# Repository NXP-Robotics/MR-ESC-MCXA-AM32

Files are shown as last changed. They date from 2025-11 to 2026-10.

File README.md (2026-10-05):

# NXP AM32 ESC based on the MCXA133

MR-ESC-MCXA-AM32 is a proof of concept Drone motor ESC (Electronic Speed Controller) motor controller, 
using NXP MCXA133 MCU and running the open-source AM32 software.
A limited number of prototype hardware samples may be available, please contact your local NXP representative. 

> [!NOTE]
> AM32 support for the MCXA133 has already been merged in mainline AM32: [AM32 application](https://github.com/am32-firmware/am32) and [AM32 bootloader](https://github.com/am32-firmware/AM32-bootloader).
> Build target for MCXA133 in main application is "FRDM_A153" and "AM32_A153_BOOTLOADER_PB2" in bootloader.
>
> Hex files can be downloaded from the official AM32 configurator: [AM32 configurator downloads](https://am32.ca/downloads)            
> AM32 Motor Control Application: AM32_FRDM_A153_x.xx.hex; AM32 Bootloader: AM32_A153_BOOTLOADER_PB2_Vxx.hex
>
> Flash board using the 6-pin JST-SH connector ([Pixhawk Debug Mini](https://docs.px4.io/main/en/debug/swd_debug#pixhawk-debug-mini))
> Do note that when flashing with MCU-LINK, pin 3 should be removed.
> 
> Design files are made with KiCAD.

> [!IMPORTANT]
This design is not supported by NXP motor control framework tools (it could of course be made to run with modifications)

MR-ESC-MCXA-AM32 with wires

<details>
<summary><h1><strong>More pictures</strong></h1></summary>

MR-ESC-MXCA-AM32 top
MR-ESC-MXCA-AM32 bottom
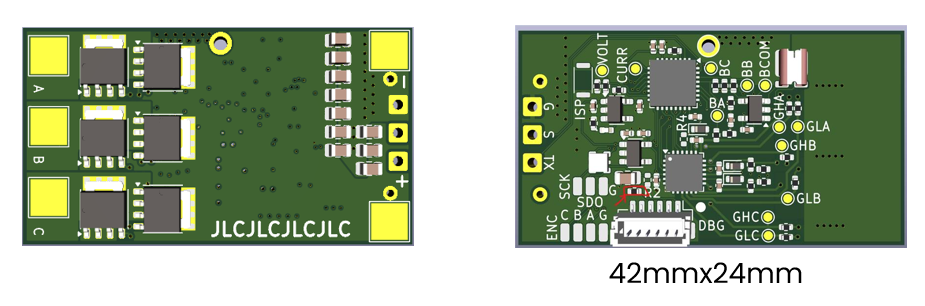
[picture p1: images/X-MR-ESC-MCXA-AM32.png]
Rendering of x-MR-ESC-MCXA-AM32 board


</details>

## Board overview

All pin data below comes from the KiCad design files in this repository.

Each card shows, per pin, the **function**, the **net name in the schematic** and the **MCU pad**
the signal ends up on. Most connections are solder pads; the only connector is the debug port.

<!-- overview:top -->
<picture>
  <source media="(prefers-color-scheme: dark)" srcset="images/overview-top-dark.svg">
  MR-ESC-MCXA-AM32 top view with labels
</picture>
<!-- /overview -->

<!-- overview-list:top -->
Not visible here: [PWR BATTERY](#esc-pwr-battery) (bottom view) · [MOTOR PHASES](#esc-motor-phases) (bottom view)
<!-- /overview-list -->

Bottom side, with the battery and motor pads:

<!-- overview:bottom -->
<picture>
  <source media="(prefers-color-scheme: dark)" srcset="images/overview-bottom-dark.svg">
  MR-ESC-MCXA-AM32 bottom view with labels
</picture>
<!-- /overview -->

## Connector index

<!-- index -->
| Ref | Function | Connector | Details |
|---|---|---|---|
| [ESC ENC](#esc-enc-encoder) ENCODER | Spare MCU pins for a quadrature encoder, solder pads | Four pads marked A, B, I and G, 3.3 V logic |  |
| [ESC MOTOR](#esc-motor-phases) PHASES | Three motor phase outputs | Three solder pads on the bottom side, marked A, B and C |  |
| [ESC PWR](#esc-pwr-battery) BATTERY | Battery input, 6 to 24 V (2S to 6S LiPo) | Two solder pads on the bottom side, marked + and - |  |
| [ESC RC](#esc-rc-signal) SIGNAL | Throttle input and telemetry output, solder pads | Three wire pads marked S, G and TX, 3.3 V logic |  |
| [ESC RGB](#esc-rgb-led-chain) LED CHAIN | Output of the on-board RGB LED chain, solder pads | Three pads marked SDO, SCK and G, 3.3 V logic |  |
| [ESC J13](#esc-j13-debug) DEBUG | SWD debug and console (DS-009 debug mini) | JST-SH 1x6 (BM06B-SRSS-TB) |  |
<!-- /index -->

## Power and motor

<!-- heading:main/PWR -->
### ESC PWR BATTERY
<!-- /heading -->

<!-- pinout:main/PWR -->
<picture>
  <source media="(prefers-color-scheme: dark)" srcset="images/main-PWR-dark.svg">
  ESC PWR BATTERY pinout
</picture>

Solder the battery leads here. Input range is 6 to 24 V, so 2S to 6S LiPo. The 5 V and 3.3 V rails come from two TPS7B92 linear regulators on this input; below about 6 V the 5 V rail drops out. All parts on the battery rail are rated 35 V or more (capacitors 35 V, regulators 40 V, FETs 80 V), which leaves margin for a full 6S pack at 25.2 V. Keep the 470 µF capacitor across the pads when you use long battery leads.

> [!CAUTION]
> There is no reverse polarity protection. Check + and - before you connect a battery.
<!-- /pinout -->

<!-- heading:main/MOTOR -->
### ESC MOTOR PHASES
<!-- /heading -->

<!-- pinout:main/MOTOR -->
<picture>
  <source media="(prefers-color-scheme: dark)" srcset="images/main-MOTOR-dark.svg">
  ESC MOTOR PHASES pinout
</picture>

Each phase is a half bridge of two PSMN3R3-80 FETs (80 V), driven by the gate driver U2. Swap any two phases to reverse the motor direction. The phase voltages also feed the back-EMF comparators of the MCU, which is how the ESC senses the rotor position.
<!-- /pinout -->

## Control

<!-- heading:main/RC -->
### ESC RC SIGNAL
<!-- /heading -->

<!-- pinout:main/RC -->
<picture>
  <source media="(prefers-color-scheme: dark)" srcset="images/main-RC-dark.svg">
  ESC RC SIGNAL pinout
</picture>

S is the throttle signal from the flight controller. The AM32 port for this MCU detects the input type by itself and supports DShot300, DShot600 (both also as bidirectional DShot) and normal servo PWM (1 to 2 ms, up to 400 Hz). DShot150 and other protocols are not supported. AM32 reads the signal with a CTIMER0 capture input and, for bidirectional DShot, switches the same pin to LPSPI0 to send the RPM telemetry back on the signal wire. TX is the AM32 serial telemetry output on LPUART1, 115200 baud, for a flight controller ESC telemetry input.

> [!NOTE]
> The signal input is 3.3 V logic. Do not connect it to a 5 V PWM source without a level shifter.
<!-- /pinout -->

<!-- heading:main/J13 -->
### ESC J13 DEBUG
<!-- /heading -->

<!-- pinout:main/J13 -->
<picture>
  <source media="(prefers-color-scheme: dark)" srcset="images/main-J13-dark.svg">
  ESC J13 DEBUG pinout
</picture>

Flash and debug the MCU over SWD with any probe that supports the DS-009 debug mini cable. Pins 2 and 3 are LPUART0 on the MCU, free for a console; AM32 sends its telemetry on LPUART1 (the TX pad) instead. Pin 1 is a 3.3 V reference output for the probe.

> [!WARNING]
> Pin 1 is a reference output, not a supply input. Never power the board from it.

> [!IMPORTANT]
> Pin 3 should be removed when debugging with an MCU-LINK.
<!-- /pinout -->

## Expansion pads

<!-- heading:main/ENC -->
### ESC ENC ENCODER
<!-- /heading -->

<!-- pinout:main/ENC -->
<picture>
  <source media="(prefers-color-scheme: dark)" srcset="images/main-ENC-dark.svg">
  ESC ENC ENCODER pinout
</picture>

Prepared for an encoder on wheeled robots, where the ESC needs odometry. The AM32 firmware does not use them yet; it only drives A and I as debug outputs. Nothing else on the board is connected to these pins.
<!-- /pinout -->

<!-- heading:main/RGB -->
### ESC RGB LED CHAIN
<!-- /heading -->

<!-- pinout:main/RGB -->
<picture>
  <source media="(prefers-color-scheme: dark)" srcset="images/main-RGB-dark.svg">
  ESC RGB LED CHAIN pinout
</picture>

The MCU drives one APA102-type RGB LED (U5) on LPSPI1. These pads are the data and clock outputs of that LED, so more LEDs of the same type can be chained from here.
<!-- /pinout -->

## Test pads

Thirteen round pads on the top side, named on the silkscreen. They are probe points for a scope
or meter, not for wires.

| Pad | Net | MCU pin | What you see there |
|---|---|---|---|
| GHA, GHB, GHC | GHA, GHB, GHC | P3_1, P3_9, P3_11 drive them | Gate of the high side FET of phase A, B, C. Output of the gate driver U2. |
| GLA, GLB, GLC | GLA, GLB, GLC | P3_0, P3_8, P3_10 drive them | Gate of the low side FET of phase A, B, C. Output of the gate driver U2. |
| BA, BB, BC | BEMFA, BEMFB, BEMFC | P1_0, P1_1, P1_3 | Back-EMF of phase A, B, C, scaled down by a divider. The MCU comparator uses these to find the rotor position. |
| BCOM | BEMF_COMMON | P2_2, P2_3 | Virtual star point: the three phase dividers joined. Reference for the back-EMF comparator. |
| VOLT | VOLTSENSE | P2_16 (ADC0 channel 6) | Battery voltage, scaled down by a divider. |
| CURR | CURRENT | P2_7 (ADC0 channel 7) | Output of the INA180 current amplifier: motor current as a voltage. |
| GND | GND |  | Ground for the probe. |

## Buttons and switches

<!-- switches -->
| Ref | Board | Function | Type | Notes |
|---|---|---|---|---|
| SW1 ISP | ESC | ISP boot button | Tactile switch | Hold it while power comes up to start the MCU boot ROM in ISP mode (P3_29 pulled low). Normal boot otherwise. |
<!-- /switches -->

## AM32 firmware

The board runs the open AM32 firmware. The firmware fork for this MCU, the hex files and how to
flash them are in the
[MR-ESC-MCXA-AM32 README](https://github.com/NXP-Robotics/MR-ESC-MCXA-AM32#readme).

Settings are changed with the [AM32 web configurator](https://am32.ca) over the signal wire,
pad S. Connect it either through the flight controller (Betaflight passthrough) or with a
serial link to a PC. No extra connector is needed. The input protocols the firmware accepts are
listed on the [RC SIGNAL card](#esc-rc-signal).

Useful pages on the AM32 wiki:

- [ESC settings explained](https://wiki.am32.ca/guides/ESC-Settings-Explained.html): what every setting does.
- [Recommended settings for freestyle drones](https://wiki.am32.ca/general/Recommended-Settings-For-Freestyle.html).
- [Flashing a single ESC](https://wiki.am32.ca/guides/AM32--single-ESC-Flashing-Tutorial.html).
- [PC link with an Arduino](https://wiki.am32.ca/guides/Arduino-PC-Link.html): a serial link to the signal wire without a flight controller.
- [Hardware design notes](https://wiki.am32.ca/development/Hardware-Design.html): for changes to the board design.
- [EEPROM format](https://wiki.am32.ca/development/Open-ESC-EEPROM-Format.html): where the settings live in flash.

> [!TIP]
> AM32 beeps through the motor at power up and after a settings change. Connect a motor before you look for the beep codes.

## Notes

- The debug port follows the Dronecode
  [DS-009 connector standard](https://github.com/pixhawk/Pixhawk-Standards/blob/master/DS-009%20Pixhawk%20Connector%20Standard.pdf)
  (debug mini), so a standard 6-pin debug cable fits.

> [!WARNING]
> The board has no reverse polarity protection and no input fuse. Wrong polarity on the battery pads destroys it.

## Downloads

This reference as an [A4 PDF](MR-ESC-MCXA-AM32-hardware-reference.pdf), and all cards on one
A4 landscape sheet: [cheat sheet PDF](MR-ESC-MCXA-AM32-cheatsheet.pdf).

NXP and the NXP logo are registered trademarks of NXP B.V. This document is maintained by the
community and is not an official NXP publication.

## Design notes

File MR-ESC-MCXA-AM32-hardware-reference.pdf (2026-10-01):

Connections of the NXP MR-ESC-MCXA-AM32, a small brushless motor controller (ESC) built around the MCXA153 or MCXA133

MCU and running the open AM32 firmware. All data comes from the KiCad design in the MR-ESC-MCXA-AM32 repository. (https://github.com/NXP-Robotics/MR-ESC-MCXA-AM32)

Each card shows, per pin, the function, the net name in the schematic and the MCU pad the signal ends up on. Most connections are

solder pads; the only connector is the debug port.

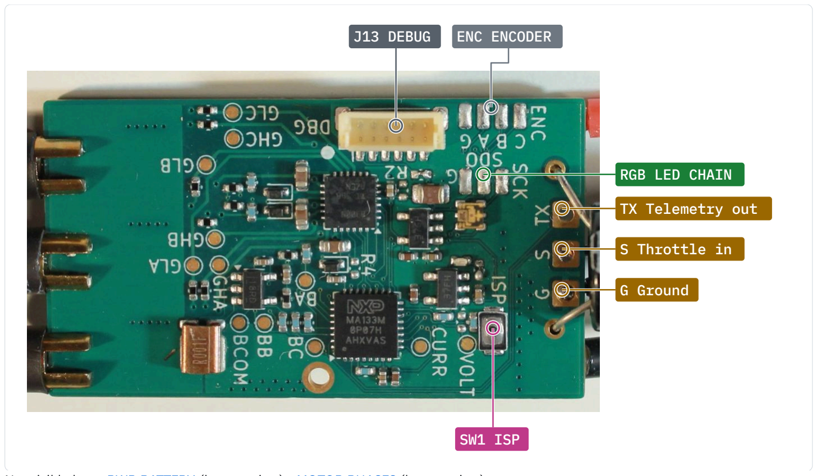
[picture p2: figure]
RGB LED CHAIN; TX Telemetry out; S Throttle in; G Ground; J13 DEBUG; ENC ENCODER; SW1 ISP

Not visible here: PWR BATTERY (bottom view) · MOTOR PHASES (bottom view)

Bottom side, with the battery and motor pads:

# MR-ESC-MCXA-AM32 hardware reference

## Board overview

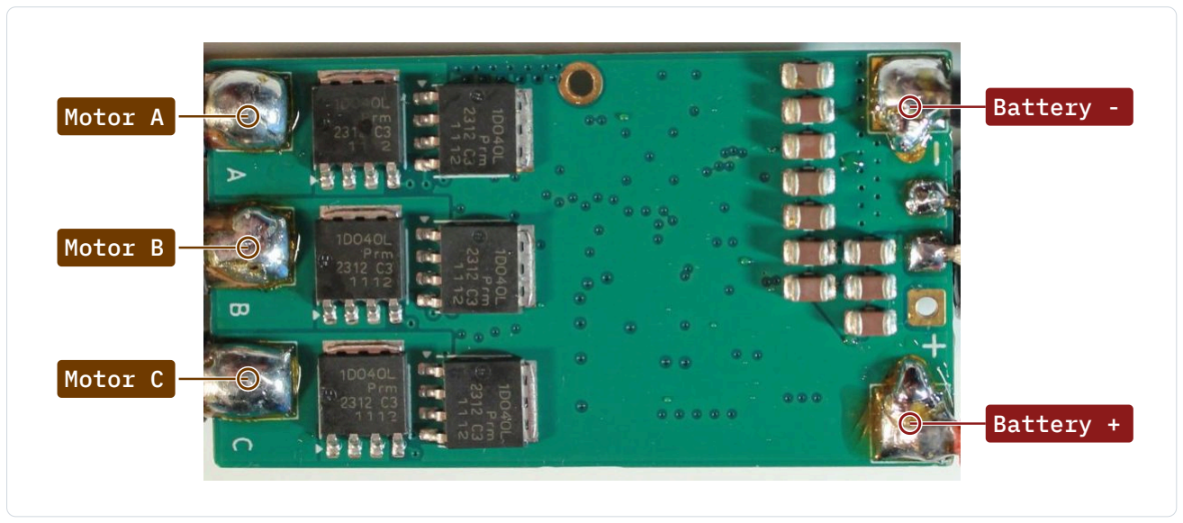
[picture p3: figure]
Motor A; Motor B; Motor C; Battery -; Battery +

Ref | Function | Connector | Details
ESC ENC ENCODER | Spare MCU pins for a quadrature encoder, solder pads | Four pads marked A, B, I and G, 3.3 V logic
ESC MOTOR PHASES | Three motor phase outputs | Three solder pads on the bottom side, marked A, B and C
ESC PWR BATTERY | Battery input, 6 to 24 V (2S to 6S LiPo) | Two solder pads on the bottom side, marked + and -
ESC RC SIGNAL | Throttle input and telemetry output, solder pads | Three wire pads marked S, G and TX, 3.3 V logic
ESC RGB LED CHAIN | Output of the on-board RGB LED chain, solder pads | Three pads marked SDO, SCK and G, 3.3 V logic
ESC J13 DEBUG | SWD debug and console (DS-009 debug mini) | JST-SH 1x6 (BM06B-SRSS-TB)

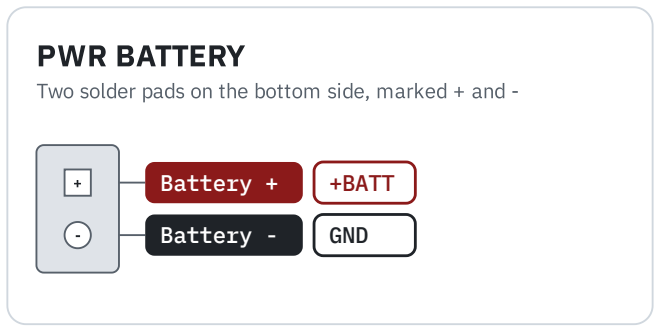
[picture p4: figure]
PWR BATTERY; Battery +; +BATT; Battery -; GND

Two solder pads on the bottom side, marked + and -

Solder the battery leads here. Input range is 6 to 24 V, so 2S to 6S LiPo. The 5 V and 3.3 V rails come from two TPS7B92 linear

regulators on this input; below about 6 V the 5 V rail drops out. All parts on the battery rail are rated 35 V or more (capacitors 35 V,

regulators 40 V, FETs 80 V), which leaves margin for a full 6S pack at 25.2 V. Keep the 470 µF capacitor across the pads when you

use long battery leads.

### Caution

There is no reverse polarity protection. Check + and - before you connect a battery.

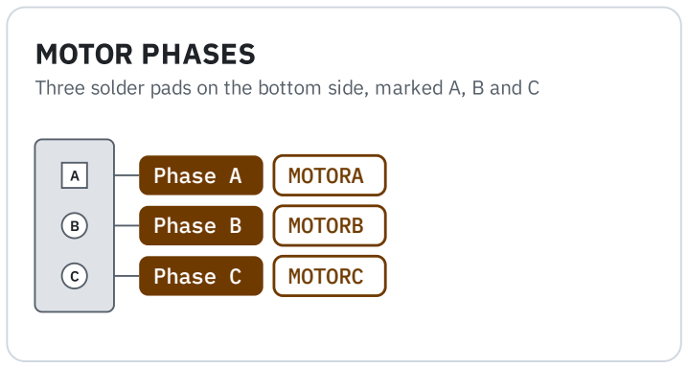
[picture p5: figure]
MOTOR PHASES; Phase A; MOTORA; Phase B; MOTORB; Phase C; MOTORC

Three solder pads on the bottom side, marked A, B and C

## Connector index

## Power and motor

### ESC PWR BATTERY

### ESC MOTOR PHASES

Each phase is a half bridge of two PSMN3R3-80 FETs (80 V), driven by the gate driver U2. Swap any two phases to reverse the motor

direction. The phase voltages also feed the back-EMF comparators of the MCU, which is how the ESC senses the rotor position.

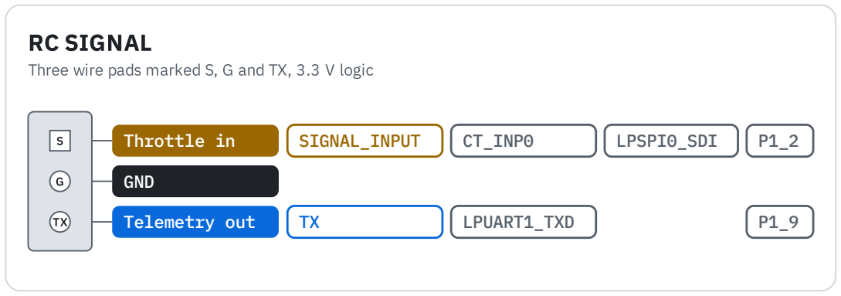
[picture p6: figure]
RC SIGNAL; GND; Telemetry out; LPUART1_TXD

Three wire pads marked S, G and TX, 3.3 V logic

S | Throttle in | SIGNAL_INPUT | CT_INP0 | LPSPI0_SDI | P1_2

S is the throttle signal from the flight controller. The AM32 port for this MCU detects the input type by itself and supports DShot300,

DShot600 (both also as bidirectional DShot) and normal servo PWM (1 to 2 ms, up to 400 Hz). DShot150 and other protocols are

not supported. AM32 reads the signal with a CTIMER0 capture input and, for bidirectional DShot, switches the same pin to LPSPI0 to

send the RPM telemetry back on the signal wire. TX is the AM32 serial telemetry output on LPUART1, 115200 baud, for a flight

controller ESC telemetry input.

### Note

The signal input is 3.3 V logic. Do not connect it to a 5 V PWM source without a level shifter.

## J13 DEBUG

JST-SH 1x6 (BM06B-SRSS-TB) · DS-009 debug mini · 3.3 V logic

1 | VREF 3.3V | +3.3V
2 | UART TX | NC/TDI | LPUART0_TXD | P0_3
3 | UART RX | SWO/TDO | LPUART0_RXD | P0_2
4 | SWDIO | SWDIO/TMS | | P0_0
5 | SWCLK | SWCLK/TCLK | | P0_1
6 | GND

Flash and debug the MCU over SWD with any probe that supports the DS-009 debug mini cable. Pins 2 and 3 are LPUART0 on the

MCU, free for a console; AM32 sends its telemetry on LPUART1 (the TX pad) instead. Pin 1 is a 3.3 V reference output for the probe.

### Warning

Pin 1 is a reference output, not a supply input. Never power the board from it.

## Control

### ESC RC SIGNAL

### ESC J13 DEBUG

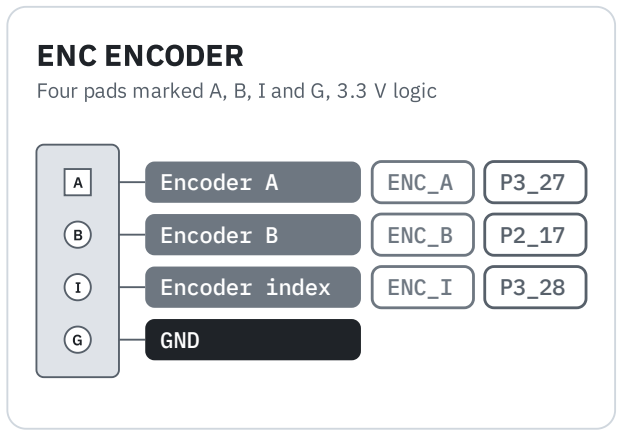
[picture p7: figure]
ENC ENCODER; Encoder A; ENC_A; Encoder B; ENC_B; Encoder index; ENC_I; GND

Four pads marked A, B, I and G, 3.3 V logic

Prepared for an encoder on wheeled robots, where the ESC needs odometry. The AM32 firmware does not use them yet; it only drives

A and I as debug outputs. Nothing else on the board is connected to these pins.

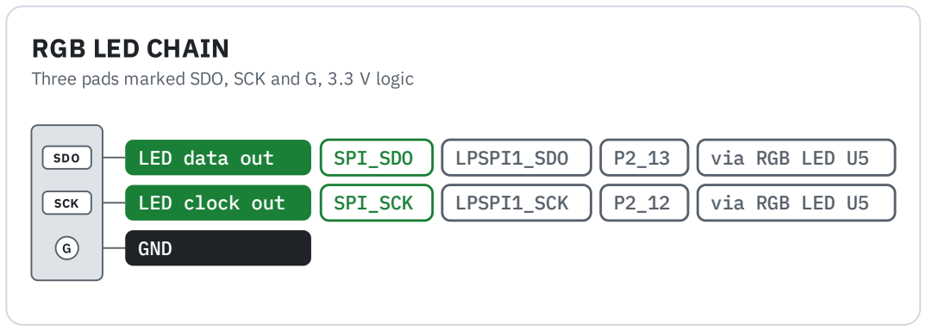
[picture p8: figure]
RGB LED CHAIN; GND

Three pads marked SDO, SCK and G, 3.3 V logic

SDO | LED data out | SPI_SDO | LPSPI1_SDO | P2_13 | via RGB LED U5
SCK | LED clock out | SPI_SCK | LPSPI1_SCK | P2_12 | via RGB LED U5

The MCU drives one APA102-type RGB LED (U5) on LPSPI1. These pads are the data and clock outputs of that LED, so more LEDs of

the same type can be chained from here.

Thirteen round pads on the top side, named on the silkscreen. They are probe points for a scope or meter, not for wires.

Pad | Net | MCU pin | What you see there
GHA, GHB, GHC | GHA, GHB, GHC | P3_1, P3_9, P3_11 drive them | Gate of the high side FET of phase A, B, C. Output of the gate driver U2.
GLA, GLB, GLC | GLA, GLB, GLC | P3_0, P3_8, P3_10 drive them | Gate of the low side FET of phase A, B, C. Output of the gate driver U2.
BA, BB, BC | BEMFA, BEMFB, BEMFC | P1_0, P1_1, P1_3 | Back-EMF of phase A, B, C, scaled down by a divider. The MCU comparator uses these to find the rotor position.
BCOM | BEMF_COMMON | P2_2, P2_3 | Virtual star point: the three phase dividers joined. Reference for the back-EMF comparator.
VOLT | VOLTSENSE | P2_16 (ADC0 channel 6) | Battery voltage, scaled down by a divider.

## Expansion pads

### ESC ENC ENCODER

### ESC RGB LED CHAIN

## Test pads

Pad | Net | MCU pin | What you see there
CURR | CURRENT | P2_7 (ADC0 channel 7) | Output of the INA180 current amplifier: motor current as a voltage.
GND | GND | | Ground for the probe.
Ref | Board | Function | Type | Notes
SW1 ISP | ESC | ISP boot button | Tactile switch | Hold it while power comes up to start the MCU boot ROM in ISP mode (P3_29 pulled low). Normal boot otherwise.

The board runs the open AM32 firmware. The firmware fork for this MCU, the hex files and how to flash them are in the MR-ESC-

MCXA-AM32 README. (https://github.com/NXP-Robotics/MR-ESC-MCXA-AM32#readme)

Settings are changed with the AM32 web configurator (https://am32.ca/) over the signal wire, pad S. Connect it either through the flight controller

(Betaflight passthrough) or with a serial link to a PC. No extra connector is needed. The input protocols the firmware accepts are

listed on the RC SIGNAL card.

Useful pages on the AM32 wiki:

ESC settings explained: (https://wiki.am32.ca/guides/ESC-Settings-Explained.html) what every setting does.

Recommended settings for freestyle drones. (https://wiki.am32.ca/general/Recommended-Settings-For-Freestyle.html)

Flashing a single ESC. (https://wiki.am32.ca/guides/AM32--single-ESC-Flashing-Tutorial.html)

PC link with an Arduino: (https://wiki.am32.ca/guides/Arduino-PC-Link.html) a serial link to the signal wire without a flight controller.

Hardware design notes: (https://wiki.am32.ca/development/Hardware-Design.html) for changes to the board design.

EEPROM format: (https://wiki.am32.ca/development/Open-ESC-EEPROM-Format.html) where the settings live in flash.

### Tip

AM32 beeps through the motor at power up and after a settings change. Connect a motor before you look for the beep codes.

Firmware, bootloader and flashing instructions are in the MR-ESC-MCXA-AM32 README. (https://github.com/NXP-Robotics/MR-ESC-MCXA-AM32#readme)

The debug port follows the Dronecode DS-009 connector standard (https://github.com/pixhawk/Pixhawk-Standards/blob/master/DS-009%20Pixhawk%20Connector%20Standard.pdf) (debug mini), so a standard 6-pin debug cable fits.

### Warning

The board has no reverse polarity protection and no input fuse. Wrong polarity on the battery pads destroys it.

This reference as an A4 PDF, (http://127.0.0.1:36261/MR-ESC-MCXA-AM32-hardware-reference.pdf) and all cards on one A4 landscape sheet: cheat sheet PDF. (http://127.0.0.1:36261/MR-ESC-MCXA-AM32-cheatsheet.pdf)

NXP and the NXP logo are registered trademarks of NXP B.V. This document is maintained by the community and is not an official

NXP publication.

## Buttons and switches

## AM32 firmware

## Notes

## Downloads

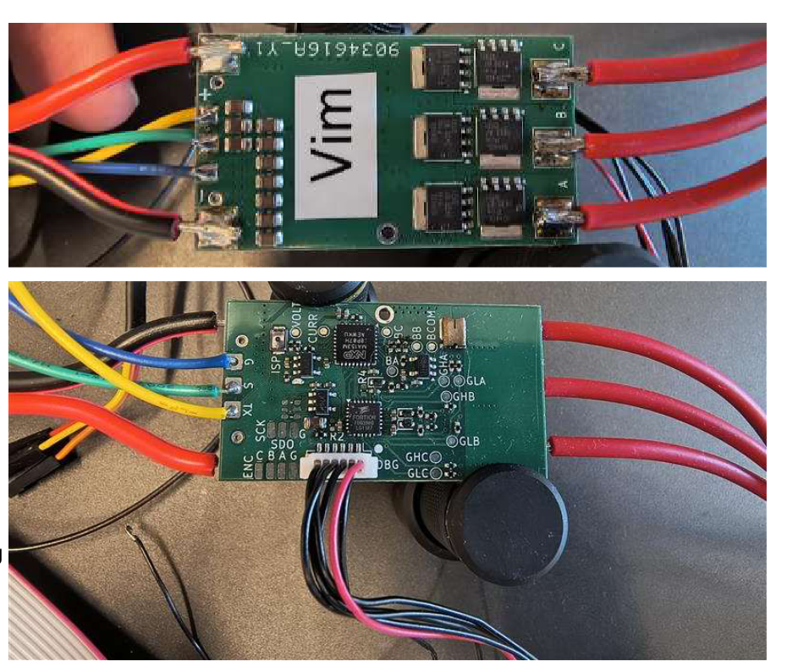
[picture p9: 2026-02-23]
images/MR-ESC-AM32_real_w_wires.png

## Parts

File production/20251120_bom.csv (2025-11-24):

Designator | Footprint | Quantity | Value | LCSC Part #
C1, C10, C15, C2, C3, C4, C5, C6, C7, C8, C9 | 0805 | 11 | 10uF 35V
C12, C19, C23 | 0402 | 3 | 1uF 16V
C13, C14, C16, C24, C25 | 0402 | 5 | 100nF 16V
C17, C20, C21 | 0603 | 3 | 1uF 50V
C18, C22 | 0402 | 2 | 100nF 50V
D1, D2, D3 | D_SOD-523 | 3 | 1N4148WT
D4 | 0402 | 1 | LED GREEN
J13 | JST_SH_BM06B-SRSS-TB_1x06-1MP_P1.00mm_Vertical | 1 | DEBUG
Q1, Q2, Q3, Q4, Q5, Q6 | LFPAK56 | 6 | PSMN1R4-40YLDX
R1, R10, R11, R12, R13, R24, R3, R8, R9 | 0402 | 9 | 10k
R14, R15, R16, R22 | 0402 | 4 | 1k
R17, R18, R19, R5, R6, R7 | 0402 | 6 | 20
R20 | 0402 | 1 | 100k
R21 | WSK1216 | 1 | 1m 3W
R23 | 0402 | 1 | 2.2k
R25 | 0402 | 1 | 100R
SW1 | TS2306A | 1 | ISPMODE
U1 | SOT-23-5 | 1 | TPS7B92033DBVR
U2 | VQFN-24-1EP_4x4mm_P0.5mm_EP2.45x2.45mm | 1 | DRV8300N or FD6288 or equivalent
U3 | HVQFN-32-1EP_5x5mm_P0.5mm_EP3.1x3.1mm | 1 | MCXA1xxVFM(Think 133)
U4 | SOT-23-5 | 1 | TPS7B92050DBVR
U5 | BB-2020BGR-TRB | 1 | BB-2020BGR-TRB
U6 | SOT-23-5 | 1 | INA180B1

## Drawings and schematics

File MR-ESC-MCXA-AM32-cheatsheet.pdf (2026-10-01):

MR-ESC-MCXA-AM32 PINOUT CHEAT SHEET | MR-ESC-MCXA-AM32 | SHEET 1 / 1

## MOTOR PHASES

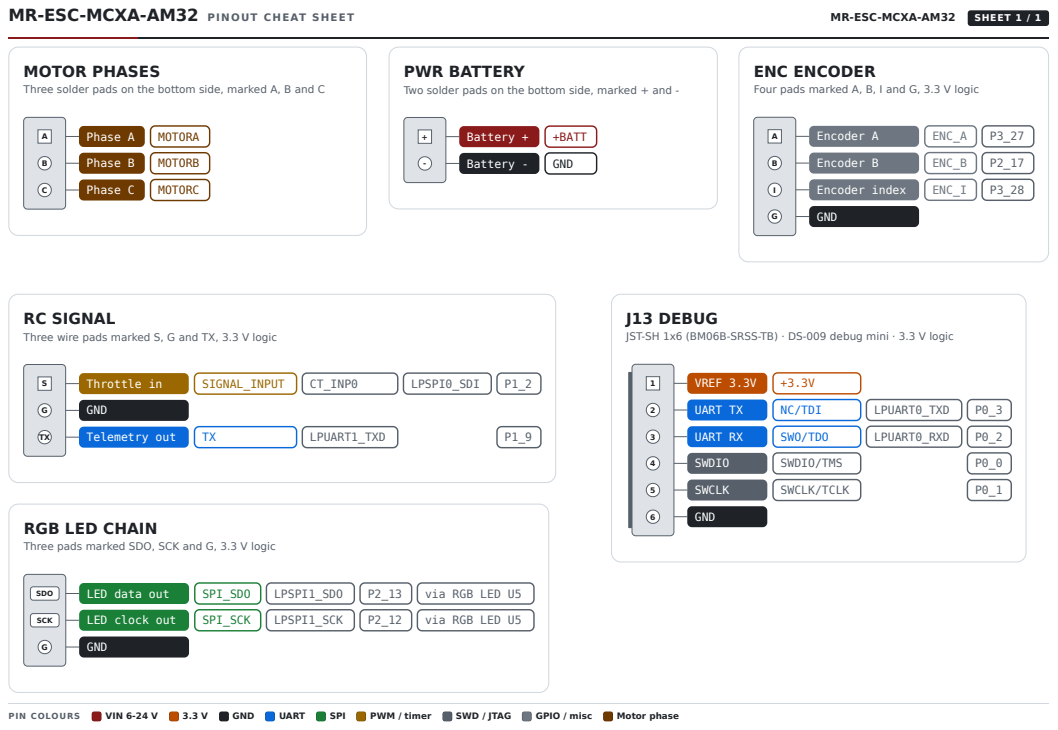
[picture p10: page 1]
Phase A; MOTORA; Phase B; MOTORB; Phase C; MOTORC; Battery +; +BATT; Battery -; GND; Encoder A; ENC_A; Encoder B; ENC_B; Encoder index; ENC_I; G GND; Throttle in; SIGNAL_INPUT; CT_INP0; LPSPI0_SDI; Telemetry out; LPUART1_TXD; VREF 3.3V; UART TX; NC/TDI; LPUART0_TXD; UART RX; SWO/TDO; LPUART0_RXD; SWDIO; SWDIO/TMS; SWCLK; SWCLK/TCLK; 6 GND; SDO; LED data out; SPI_SDO; LPSPI1_SDO; via RGB LED U5; SCK; LED clock out; SPI_SCK; LPSPI1_SCK; PIN COLOURS; VIN 6-24 V; UART; SPI; PWM / timer; SWD / JTAG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

PWR BATTERY
Two solder pads on the bottom side, marked + and -

ENC ENCODER
Four pads marked A, B, I and G, 3.3 V logic

Three solder pads on the bottom side, marked A, B and C

RC SIGNAL
Three wire pads marked S, G and TX, 3.3 V logic

J13 DEBUG
JST-SH 1x6 (BM06B-SRSS-TB) · DS-009 debug mini · 3.3 V logic

RGB LED CHAIN
Three pads marked SDO, SCK and G, 3.3 V logic

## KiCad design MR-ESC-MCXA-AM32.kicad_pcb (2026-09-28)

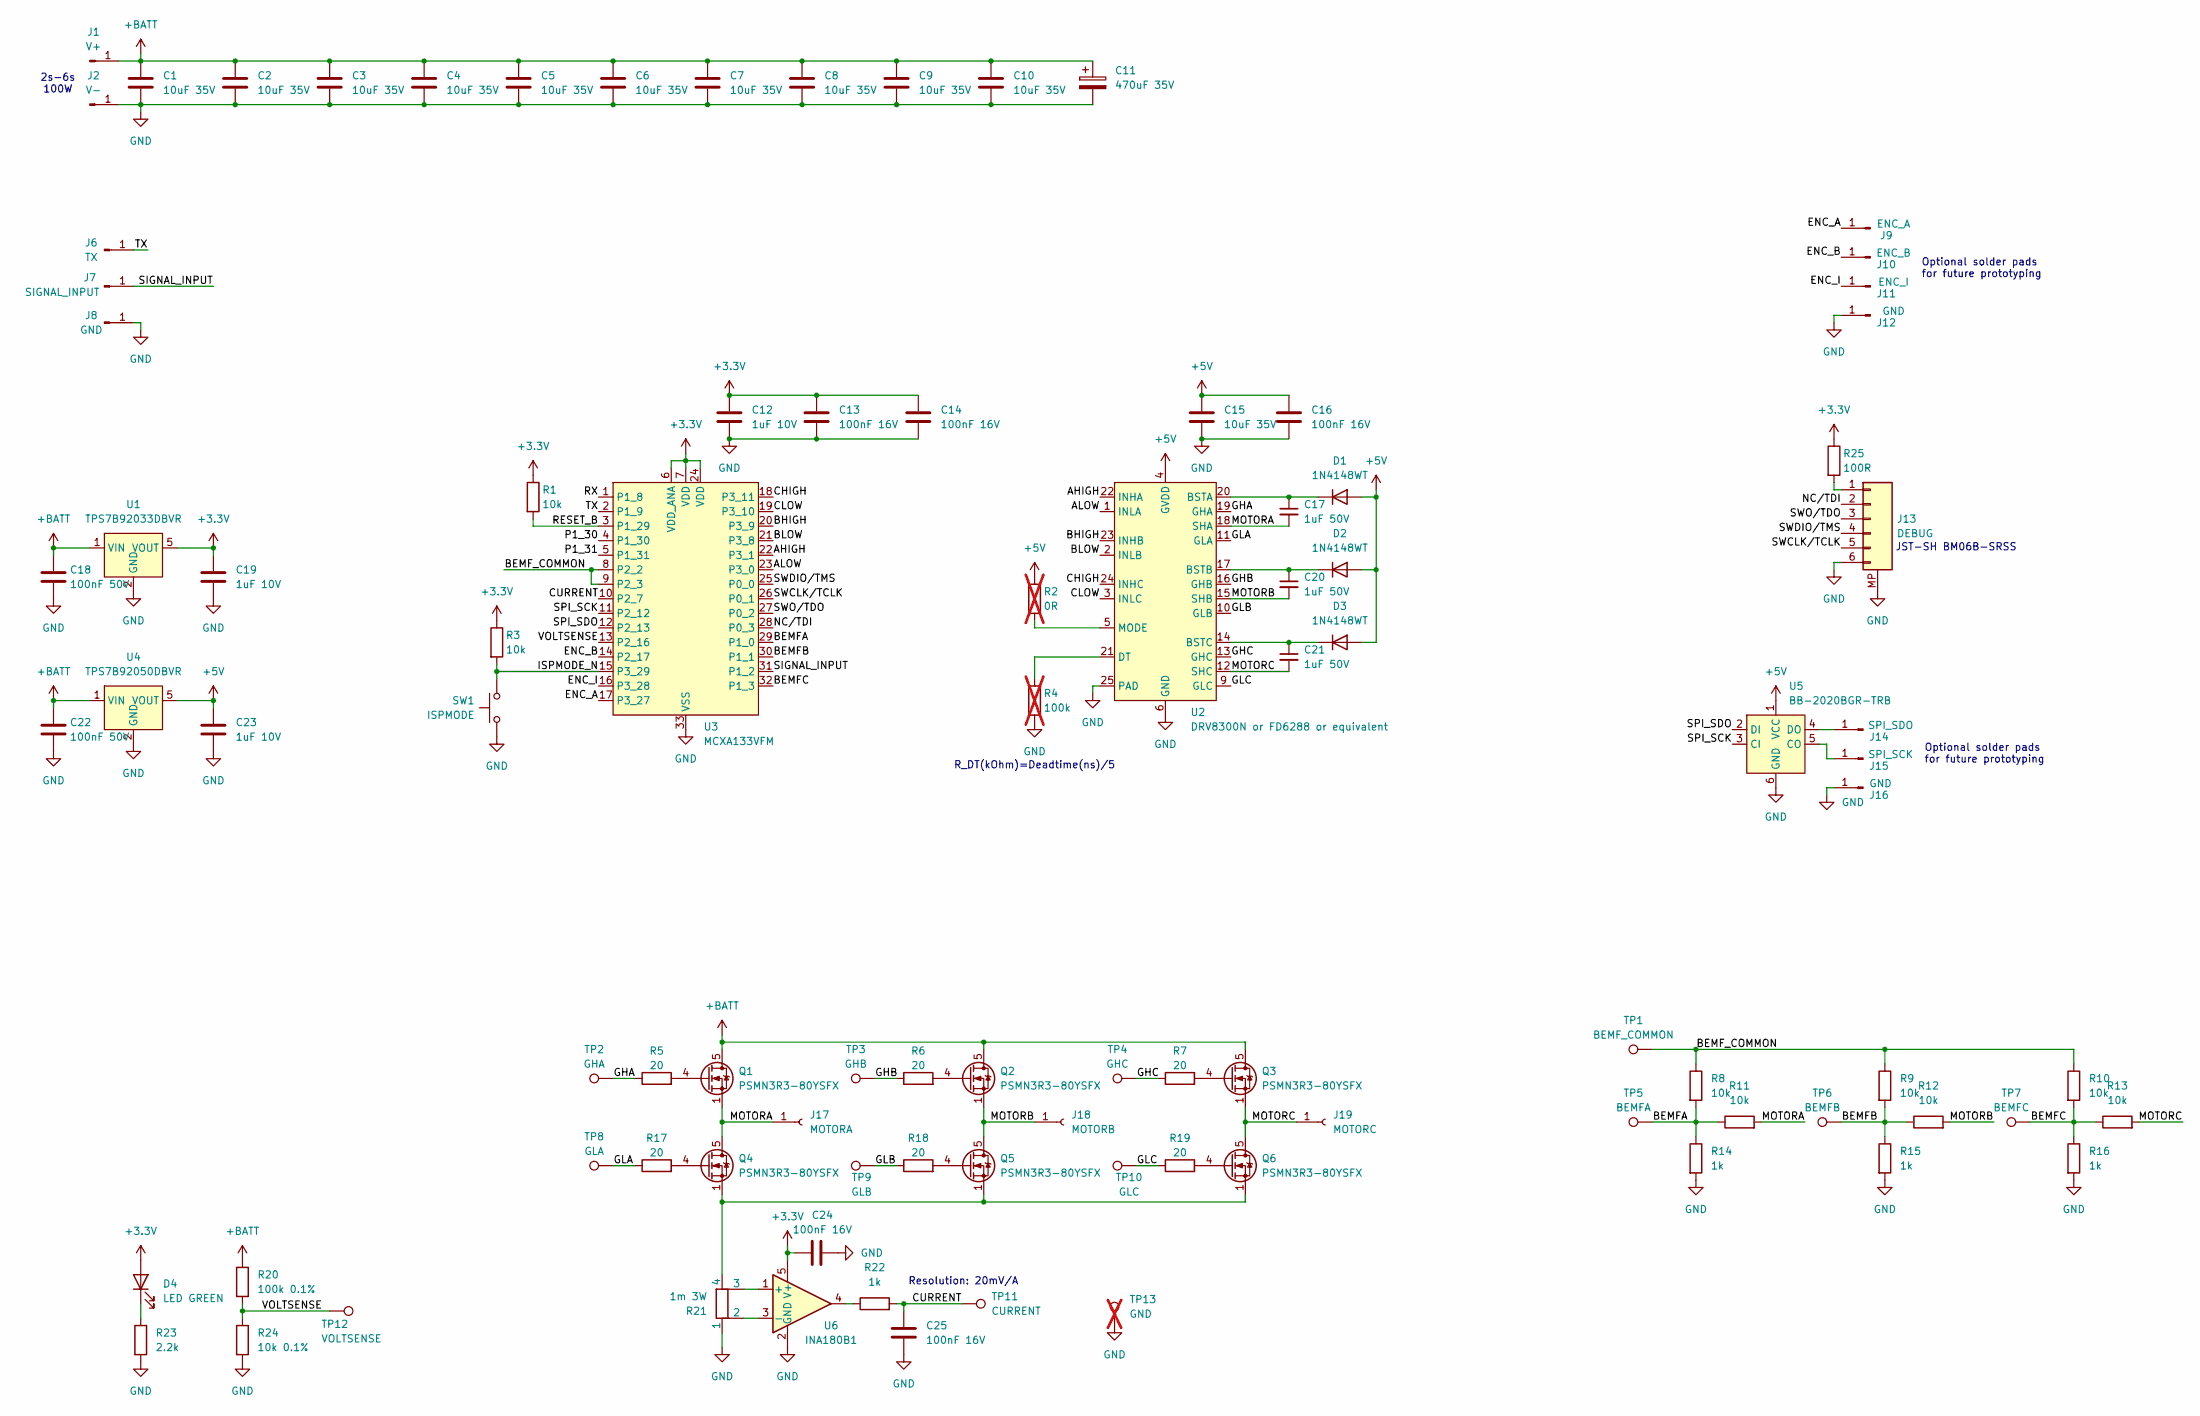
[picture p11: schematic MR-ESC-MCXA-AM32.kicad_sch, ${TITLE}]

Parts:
C1, C2, C3, C4, C5, C6, C7, C8, C9, C10, C15: 10uF 35V; C_0805_2012Metric
C11: 470uF 35V; C_Axial_L3.8mm_D2.6mm_P12.50mm_Horizontal
C12, C19, C23: 1uF 10V; C_0402_1005Metric
C13, C14, C16, C24, C25: 100nF 16V; C_0402_1005Metric
C17, C20, C21: 1uF 50V; C_0603_1608Metric
C18, C22: 100nF 50V; C_0402_1005Metric
D1, D2, D3: 1N4148WT; D_SOD-523
D4: LED GREEN; LED_0402_1005Metric
J1: V+; TestPoint_Pad_4.0x4.0mm
J2: V-; TestPoint_Pad_4.0x4.0mm
J6: TX; SolderWire-0.5sqmm_1x01_D0.9mm_OD2.1mm
J7: SIGNAL_INPUT; SolderWire-0.5sqmm_1x01_D0.9mm_OD2.1mm
J8: GND; SolderWire-0.5sqmm_1x01_D0.9mm_OD2.1mm
J9: ENC_A; SolderWirePad_1x01_SMD_1x2mm
J10: ENC_B; SolderWirePad_1x01_SMD_1x2mm
J11: ENC_I; SolderWirePad_1x01_SMD_1x2mm
J12, J16: GND; SolderWirePad_1x01_SMD_1x2mm
J13: DEBUG; JST_SH_BM06B-SRSS-TB_1x06-1MP_P1.00mm_Vertical
J14: SPI_SDO; SolderWirePad_1x01_SMD_1x2mm
J15: SPI_SCK; SolderWirePad_1x01_SMD_1x2mm
J17: MOTORA; TestPoint_Pad_4.0x4.0mm
J18: MOTORB; TestPoint_Pad_4.0x4.0mm
J19: MOTORC; TestPoint_Pad_4.0x4.0mm
Q1, Q2, Q3, Q4, Q5, Q6: PSMN3R3-80YSFX; LFPAK56
R1, R3, R8, R9, R10, R11, R12, R13: 10k; R_0402_1005Metric
R2: 0R; R_0402_1005Metric; not fitted
R4: 100k; R_0402_1005Metric; not fitted
R5, R6, R7, R17, R18, R19: 20; R_0402_1005Metric
R14, R15, R16, R22: 1k; R_0402_1005Metric
R20: 100k 0.1%; R_0402_1005Metric
R21: 1m 3W; WSK1216
R23: 2.2k; R_0402_1005Metric
R24: 10k 0.1%; R_0402_1005Metric
R25: 100R; R_0402_1005Metric
SW1: ISPMODE; TS2306A
TP1: BEMF_COMMON; TestPoint_Pad_D1.0mm
TP2: GHA; TestPoint_Pad_D1.0mm
TP3: GHB; TestPoint_Pad_D1.0mm
TP4: GHC; TestPoint_Pad_D1.0mm
TP5: BEMFA; TestPoint_Pad_D1.0mm
TP6: BEMFB; TestPoint_Pad_D1.0mm
TP7: BEMFC; TestPoint_Pad_D1.0mm
TP8: GLA; TestPoint_Pad_D1.0mm
TP9: GLB; TestPoint_Pad_D1.0mm
TP10: GLC; TestPoint_Pad_D1.0mm
TP11: CURRENT; TestPoint_Pad_D1.0mm
TP12: VOLTSENSE; TestPoint_Pad_D1.0mm
TP13: GND; TestPoint_THTPad_D2.0mm_Drill1.0mm; not fitted
U1: TPS7B92033DBVR; SOT-23-5
U2: DRV8300N or FD6288 or equivalent; VQFN-24-1EP_4x4mm_P0.5mm_EP2.45x2.45mm
U3: MCXA133VFM; HVQFN-32-1EP_5x5mm_P0.5mm_EP3.1x3.1mm
U4: TPS7B92050DBVR; SOT-23-5
U5: BB-2020BGR-TRB
U6: INA180B1; SOT-23-5

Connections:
+3.3V: C12.1, C13.1, C14.1, C19.1, C24.1, D4.2 (A), R1.1, R3.1, R25.1, U1.5 (VOUT), U3.6 (VDD_ANA), U3.7 (VDD), U3.24 (VDD), U6.5 (V+)
+5V: C15.1, C16.1, C23.1, D1.2 (A), D2.2 (A), D3.2 (A), R2.1, U2.4 (GVDD), U4.5 (VOUT), U5.1 (VCC)
+BATT: C1.1, C2.1, C3.1, C4.1, C5.1, C6.1, C7.1, C8.1, C9.1, C10.1, C11.1, C18.1, C22.1, J1.1, Q1.5 (D), Q2.5 (D), Q3.5 (D), R20.1, U1.1 (VIN), U4.1 (VIN)
/AHIGH: U2.22 (INHA), U3.22 (P3_1)
/ALOW: U2.1 (INLA), U3.23 (P3_0)
/BEMFA: R8.2, R11.1, R14.1, TP5.1, U3.29 (P1_0)
/BEMFB: R9.2, R12.1, R15.1, TP6.1, U3.30 (P1_1)
/BEMFC: R10.2, R13.1, R16.1, TP7.1, U3.32 (P1_3)
/BEMF_COMMON: R8.1, R9.1, R10.1, TP1.1, U3.8 (P2_2), U3.9 (P2_3)
/BHIGH: U2.23 (INHB), U3.20 (P3_9)
/BLOW: U2.2 (INLB), U3.21 (P3_8)
/CHIGH: U2.24 (INHC), U3.18 (P3_11)
/CLOW: U2.3 (INLC), U3.19 (P3_10)
/CURRENT: C25.1, R22.2, TP11.1, U3.10 (P2_7)
/ENC_A: J9.1, U3.17 (P3_27)
/ENC_B: J10.1, U3.14 (P2_17)
/ENC_I: J11.1, U3.16 (P3_28)
/GHA: R5.1, TP2.1, U2.19 (GHA)
/GHB: R6.1, TP3.1, U2.16 (GHB)
/GHC: R7.1, TP4.1, U2.13 (GHC)
/GLA: R17.1, TP8.1, U2.11 (GLA)
/GLB: R18.1, TP9.1, U2.10 (GLB)
/GLC: R19.1, TP10.1, U2.9 (GLC)
/ISPMODE_N: R3.2, SW1.1, U3.15 (P3_29)
/MOTORA: C17.2, J17.1, Q1.1 (S), Q1.2 (S), Q1.3 (S), Q4.5 (D), R11.2, U2.18 (SHA)
/MOTORB: C20.2, J18.1, Q2.1 (S), Q2.2 (S), Q2.3 (S), Q5.5 (D), R12.2, U2.15 (SHB)
/MOTORC: C21.2, J19.1, Q3.1 (S), Q3.2 (S), Q3.3 (S), Q6.5 (D), R13.2, U2.12 (SHC)
/NC/TDI: J13.2, U3.28 (P0_3)
/P1_30: U3.4 (P1_30)
/P1_31: U3.5 (P1_31)
/RESET_B: R1.2, U3.3 (P1_29)
/RX: U3.1 (P1_8)
/SIGNAL_INPUT: J7.1, U3.31 (P1_2)
/SPI_SCK: U3.11 (P2_12), U5.3 (CI)
/SPI_SDO: U3.12 (P2_13), U5.2 (DI)
/SWCLK/TCLK: J13.5, U3.26 (P0_1)
/SWDIO/TMS: J13.4, U3.25 (P0_0)
/SWO/TDO: J13.3, U3.27 (P0_2)
/TX: J6.1, U3.2 (P1_9)
/VOLTSENSE: R20.2, R24.1, TP12.1, U3.13 (P2_16)
GND: C1.2, C2.2, C3.2, C4.2, C5.2, C6.2, C7.2, C8.2, C9.2, C10.2, C11.2, C12.2, C13.2, C14.2, C15.2, C16.2, C18.2, C19.2, C22.2, C23.2, C24.2, C25.2, J2.1, J8.1, J12.1, J13.6, J13.MP, J16.1, R4.2, R14.2, R15.2, R16.2, R21.1, R23.2, R24.2, SW1.2, TP13.1, U1.2 (GND), U2.6 (GND), U2.25 (PAD), U3.33 (VSS), U4.2 (GND), U5.6 (GND), U6.2 (GND)
unnamed: C17.1, D1.1 (K), U2.20 (BSTA)
unnamed: C20.1, D2.1 (K), U2.17 (BSTB)
unnamed: C21.1, D3.1 (K), U2.14 (BSTC)
unnamed: D4.1 (K), R23.1
unnamed: J13.1, R25.2
unnamed: J14.1, U5.4 (DO)
unnamed: J15.1, U5.5 (CO)
unnamed: Q1.4 (G), R5.2
unnamed: Q2.4 (G), R6.2
unnamed: Q3.4 (G), R7.2
unnamed: Q4.4 (G), R17.2
unnamed: Q4.1 (S), Q4.2 (S), Q4.3 (S), Q5.1 (S), Q5.2 (S), Q5.3 (S), Q6.1 (S), Q6.2 (S), Q6.3 (S), R21.4
unnamed: Q5.4 (G), R18.2
unnamed: Q6.4 (G), R19.2
unnamed: R22.1, U6.4
unnamed: R4.1, U2.21 (DT)
unnamed: R2.2, U2.5 (MODE)
unnamed: R21.3, U6.1 (+)
unnamed: R21.2, U6.3 (-)

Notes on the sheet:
Optional solder pads for future prototyping
JST-SH BM06B-SRSS
R_DT(kOhm)=Deadtime(ns)/5
Resolution: 20mV/A
2s-6s 100W

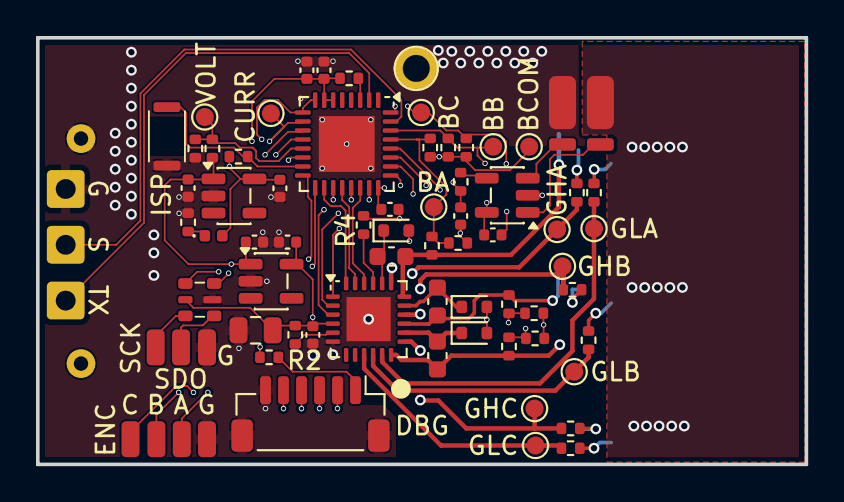
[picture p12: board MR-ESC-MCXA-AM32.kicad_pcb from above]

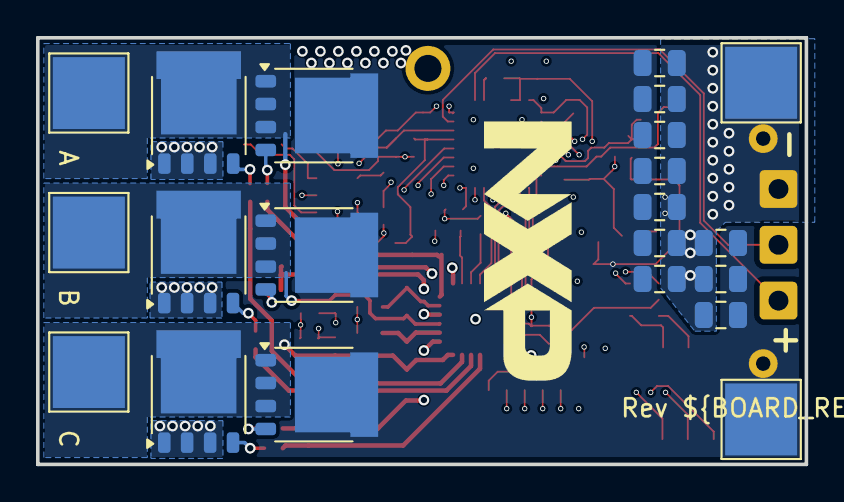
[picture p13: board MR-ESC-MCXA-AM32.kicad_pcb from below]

Board: 4 copper layers, 42.7 x 23.7 mm, 96 parts (21 on the bottom side), 57 nets.

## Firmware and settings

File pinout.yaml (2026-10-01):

# Pinout data for the MR-ESC-MCXA-AM32 hardware reference. The cards, photos and tables are generated from this file.

meta:
  title: MR-ESC-MCXA-AM32 hardware reference
  short_title: MR-ESC-MCXA-AM32
  soc: MCXA153

categories:
  vin:   {label: "VIN 6-24 V",      fill: "#8b1a1a", dark: "#f85149"}
  5v:    {label: "5 V",             fill: "#d1242f", dark: "#ff7b72"}
  3v3:   {label: "3.3 V",           fill: "#bc4c00", dark: "#f0883e"}
  gnd:   {label: "GND",             fill: "#1f2328", dark: "#6e7681"}
  uart:  {label: "UART",            fill: "#0969da", dark: "#58a6ff"}
  i2c:   {label: "I2C",             fill: "#8250df", dark: "#bc8cff"}
  spi:   {label: "SPI",             fill: "#1a7f37", dark: "#3fb950"}
  pwm:   {label: "PWM / timer",     fill: "#9a6700", dark: "#d29922"}
  can:   {label: "CAN FD",          fill: "#0a7c86", dark: "#39c5cf"}
  usb:   {label: "USB",             fill: "#a40e6b", dark: "#f778ba"}
  eth:   {label: "Ethernet",        fill: "#116329", dark: "#56d364"}
  pcie:  {label: "PCIe / M.2",      fill: "#3b3b8f", dark: "#a5b4fc"}
  debug: {label: "SWD / JTAG",      fill: "#57606a", dark: "#8b949e"}
  boot:  {label: "Boot mode",       fill: "#bf3989", dark: "#f778ba"}
  gpio:  {label: "GPIO / misc",     fill: "#6e7781", dark: "#8b949e"}
  adc:   {label: "Analog",          fill: "#bf3989", dark: "#ff9bce"}
  audio: {label: "Audio",           fill: "#7d4e00", dark: "#e3b341"}
  motor: {label: "Motor phase",     fill: "#6f3a00", dark: "#f0883e"}
  nc:    {label: "NC / key",        fill: "#eaeef2", dark: "#30363d", text: "#57606a"}

boards:
  main: {name: "MR-ESC-MCXA-AM32", short: ESC, tag: "ESC board"}

overviews:
  top:
    photo: ESC_TOP.JPG
    crop: [0.14, 0.02, 0.73, 0.98]
    max_px: 1020
    alt: "MR-ESC-MCXA-AM32 top view with labels"
    callouts:
      - {conn: main/J13, x: 0.520, y: 0.175, side: top}
      - {conn: main/ENC, x: 0.618, y: 0.123, side: top}
      - {conn: main/RGB, x: 0.610, y: 0.312, side: right}
      - {conn: main/RC,  x: 0.691, y: 0.408, side: right, label: "TX Telemetry out"}
      - {conn: main/RC,  x: 0.691, y: 0.522, side: right, label: "S Throttle in"}
      - {conn: main/RC,  x: 0.691, y: 0.637, side: right, label: "G Ground"}
      - {conn: main/SW1, x: 0.620, y: 0.745, side: bottom}
      - {conn: main/PWR, hidden: "bottom view"}
      - {conn: main/MOTOR, hidden: "bottom view"}
  bottom:
    photo: ESC_BOTTOM.JPG
    crop: [0.14, 0.02, 0.74, 0.98]
    max_px: 1100
    alt: "MR-ESC-MCXA-AM32 bottom view with labels"
    callouts:
      - {conn: main/PWR,   x: 0.700, y: 0.160, side: right, label: "Battery -"}
      - {conn: main/PWR,   x: 0.700, y: 0.855, side: right, label: "Battery +"}
      - {conn: main/MOTOR, x: 0.175, y: 0.181, side: left, label: "Motor A"}
      - {conn: main/MOTOR, x: 0.175, y: 0.469, side: left, label: "Motor B"}
      - {conn: main/MOTOR, x: 0.175, y: 0.757, side: left, label: "Motor C"}

connectors:
  - ref: PWR
    board: main
    name: BATTERY
    cat: vin
    function: "Battery input, 6 to 24 V (2S to 6S LiPo)"
    type: "Two solder pads on the bottom side, marked + and -"
    source: "MR-ESC-MCXA-AM32.kicad_sch"
    layout: single
    notes: >
      Solder the battery leads here. Input range is 6 to 24 V, so 2S to 6S LiPo. The 5 V and
      3.3 V rails come from two TPS7B92 linear regulators on this input; below about 6 V the
      5 V rail drops out. All parts on the battery rail are rated 35 V or more (capacitors 35 V,
      regulators 40 V, FETs 80 V), which leaves margin for a full 6S pack at 25.2 V. Keep the
      470 µF capacitor across the pads when you use long battery leads.
    alerts:
      - {type: caution, text: "There is no reverse polarity protection. Check + and - before you connect a battery."}
    pins:
      - {n: "+", net: "+BATT", cat: vin, label: "Battery +"}
      - {n: "-", net: GND, cat: gnd, label: "Battery -"}

  - ref: MOTOR
    board: main
    name: PHASES
    cat: motor
    function: "Three motor phase outputs"
    type: "Three solder pads on the bottom side, marked A, B and C"
    source: "MR-ESC-MCXA-AM32.kicad_sch"
    layout: single
    notes: >
      Each phase is a half bridge of two PSMN3R3-80 FETs (80 V), driven by the gate driver U2. Swap any
      two phases to reverse the motor direction. The phase voltages also feed the back-EMF
      comparators of the MCU, which is how the ESC senses the rotor position.
    pins:
      - {n: A, net: MOTORA, cat: motor, label: "Phase A"}
      - {n: B, net: MOTORB, cat: motor, label: "Phase B"}
      - {n: C, net: MOTORC, cat: motor, label: "Phase C"}

  - ref: RC
    board: main
    name: SIGNAL
    cat: pwm
    function: "Throttle input and telemetry output, solder pads"
    type: "Three wire pads marked S, G and TX, 3.3 V logic"
    source: "MR-ESC-MCXA-AM32.kicad_sch"
    layout: single
    notes: >
      S is the throttle signal from the flight controller. The AM32 port for this MCU detects the
      input type by itself and supports DShot300, DShot600 (both also as bidirectional DShot) and
      normal servo PWM (1 to 2 ms, up to 400 Hz). DShot150 and other protocols are not supported.
      AM32 reads the signal with a CTIMER0 capture input and, for bidirectional DShot, switches
      the same pin to LPSPI0 to send the RPM telemetry back on the signal wire. TX is the AM32 serial telemetry
      output on LPUART1, 115200 baud, for a flight controller ESC telemetry input.
    alerts:
      - {type: note, text: "The signal input is 3.3 V logic. Do not connect it to a 5 V PWM source without a level shifter."}
    pins:
      - {n: S,  net: SIGNAL_INPUT, cat: pwm,  label: "Throttle in", pad: P1_2, alt: [CT_INP0, LPSPI0_SDI]}
      - {n: G,  net: GND,          cat: gnd}
      - {n: TX, net: TX,           cat: uart, label: "Telemetry out", pad: P1_9, alt: [LPUART1_TXD]}

  - ref: J13
    board: main
    name: DEBUG
    cat: debug
    function: "SWD debug and console (DS-009 debug mini)"
    type: "JST-SH 1x6 (BM06B-SRSS-TB)"
    standard: "DS-009 debug mini"
    level: "3.3 V logic"
    source: "MR-ESC-MCXA-AM32.kicad_sch"
    layout: single
    notes: >
      Flash and debug the MCU over SWD with any probe that supports the DS-009 debug mini cable.
      Pins 2 and 3 are LPUART0 on the MCU, free for a console; AM32 sends its telemetry on
      LPUART1 (the TX pad) instead. Pin 1 is a 3.3 V reference output for the probe.
    alerts:
      - {type: warning, text: "Pin 1 is a reference output, not a supply input. Never power the board from it."}
    pins:
      - {n: 1, net: "+3.3V", cat: 3v3,   label: "VREF 3.3V"}
      - {n: 2, net: NC/TDI,  cat: uart,  label: "UART TX",  pad: P0_3, alt: [LPUART0_TXD]}
      - {n: 3, net: SWO/TDO, cat: uart,  label: "UART RX",  pad: P0_2, alt: [LPUART0_RXD]}
      - {n: 4, net: SWDIO/TMS,   cat: debug, label: "SWDIO",  pad: P0_0}
      - {n: 5, net: SWCLK/TCLK,  cat: debug, label: "SWCLK",  pad: P0_1}
      - {n: 6, net: GND, cat: gnd}
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

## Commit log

2025-11-24 Update 20251120_bom.csv
    Addiing the exact MCU part number
    [20251120_bom.csv]
2025-11-26 Updated production files
    - Grouped production files in folder. One that has JLCPCB specific formatted production files. The other has standard production files that can be used anywhere.
    - Created Gerber, BOM, position file and Step file for standard production.
    [20250416_bom.csv, 20250416_designators.csv, 20250416_positions.csv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]
2026-01-23 Add photo of pre-production physical board to readme
2026-02-23 Updated schematic, BOM and production files
    - Updated R20 and R24 to be 0.1% resistors.
    - Updated the whole BOM to have correct part numbers from DigiKey.
    - PSMN1R4-40YLDX was out of stock so replaced it with PSMN3R3-80YSFX. This also improves the ability to withstand large BEMF peaks.
    - Created new schematic and production files.
    [20251126_MR-ESC-MCXA-AM32.step, 20251126_MR-ESC-MCXA-AM32_BOM.csv, 20260223_MR-ESC-MCXA-AM32.step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]
2026-02-23 Added new schematic
2026-09-28 Updated TS2306A footprint
    Added 3D model to footprint.
2026-09-28 Updated schematic and layout to Rev A
    - Updated BOM to have DNP column
    - Changed C11 to populated
    - Added text variables
    - Added NXP logo, title and revision on silkscreen
    - Updated all parts 3D models to Kicad 9
    [MR-ESC-MCXA-AM32.kicad_pcb, MR-ESC-MCXA-AM32.kicad_sch]
2026-09-28 Removed production folder
    Removed production folder as these are generated files.
    Production files are found at the corresponding release.
    [20250416_bom.csv, 20250416_designators.csv, 20250416_positions.csv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]
2026-10-01 Add connector reference and useful links
2026-10-05 Update README.md
    - Removed all mentions of MCXA153.
    - Updated links to AM32 repo.
    - Added note on Debug connector pin 3.
